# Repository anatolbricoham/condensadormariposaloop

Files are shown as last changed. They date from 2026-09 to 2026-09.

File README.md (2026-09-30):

# Loop magnética con condensador mariposa motorizado y autoajuste (DIY)

Cálculo completo, planos de corte láser (DXF/SVG), **piezas imprimibles en 3D (STL + OpenSCAD)**,
**firmware de autoajuste para ESP32** y guía de construcción de un **condensador variable de aire
tipo mariposa (butterfly)** para antenas **loop magnéticas de HF**, con la lista de materiales y
**dónde conseguirlos en Murcia**.

> 👉 **Empieza por la [guía paso a paso](docs/guia_paso_a_paso.md).**

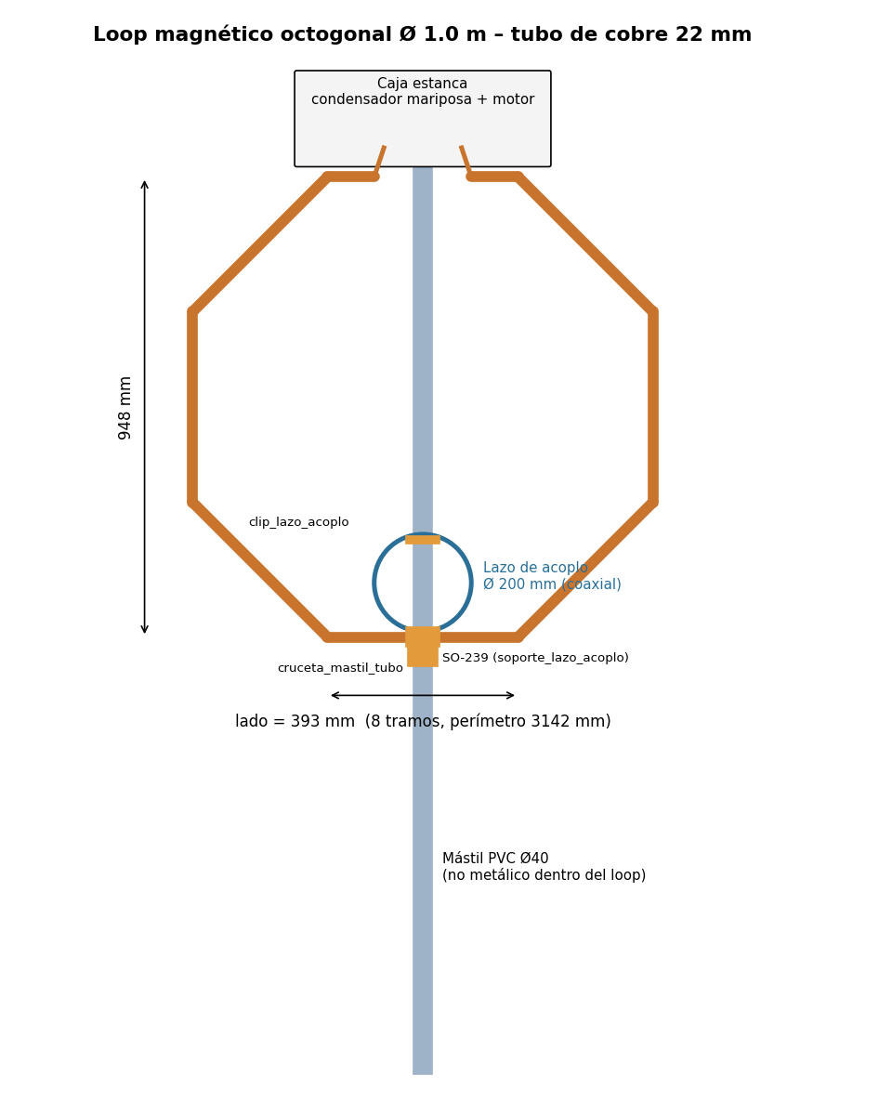
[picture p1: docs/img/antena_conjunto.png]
Antena completa


Basado en el artículo de **TA2WK** –
[High-Voltage DIY Air Capacitor for Magnetic Loop Antennas](https://www.ta2wk.com/high-voltage-diy-air-capacitor-for-magnetic-loop-antennas/)
– y en la serie de vídeos de referencia
([YouTube](https://www.youtube.com/watch?v=iPEKQIZHf5k&list=PLLFrLgZ4YFd04bd3ThvmXpGTpUq9JYBLg&index=1)).

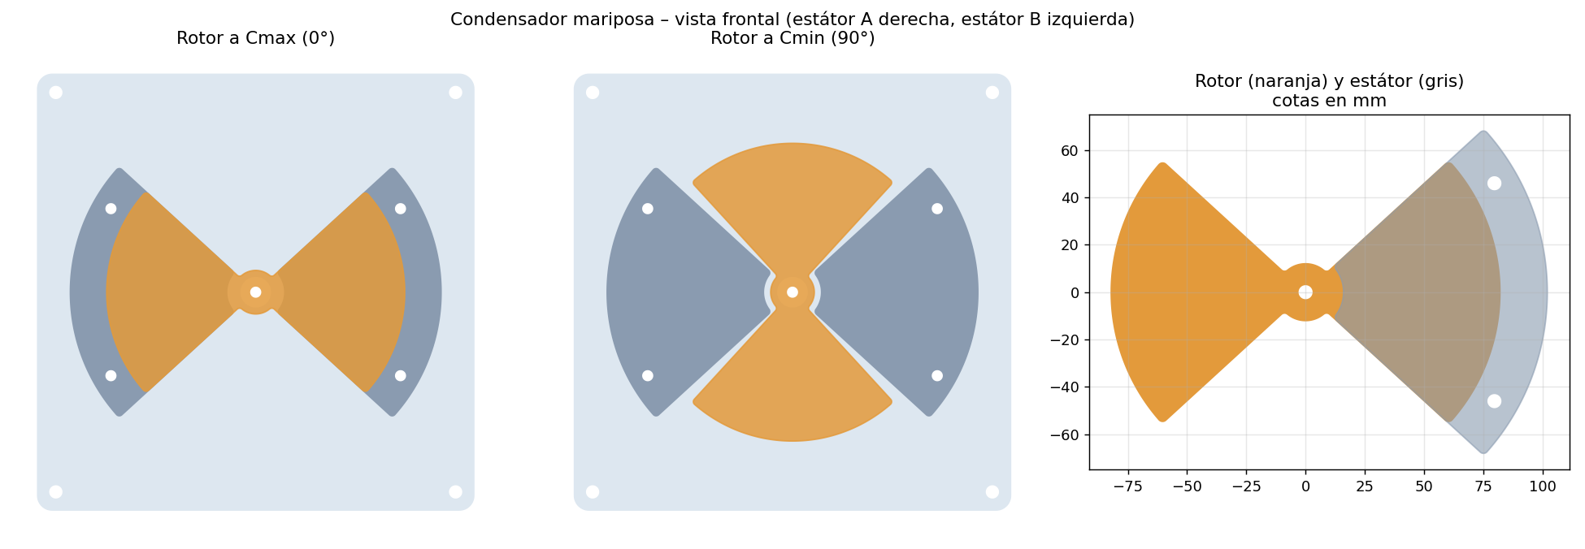
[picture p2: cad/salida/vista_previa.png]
Vista previa

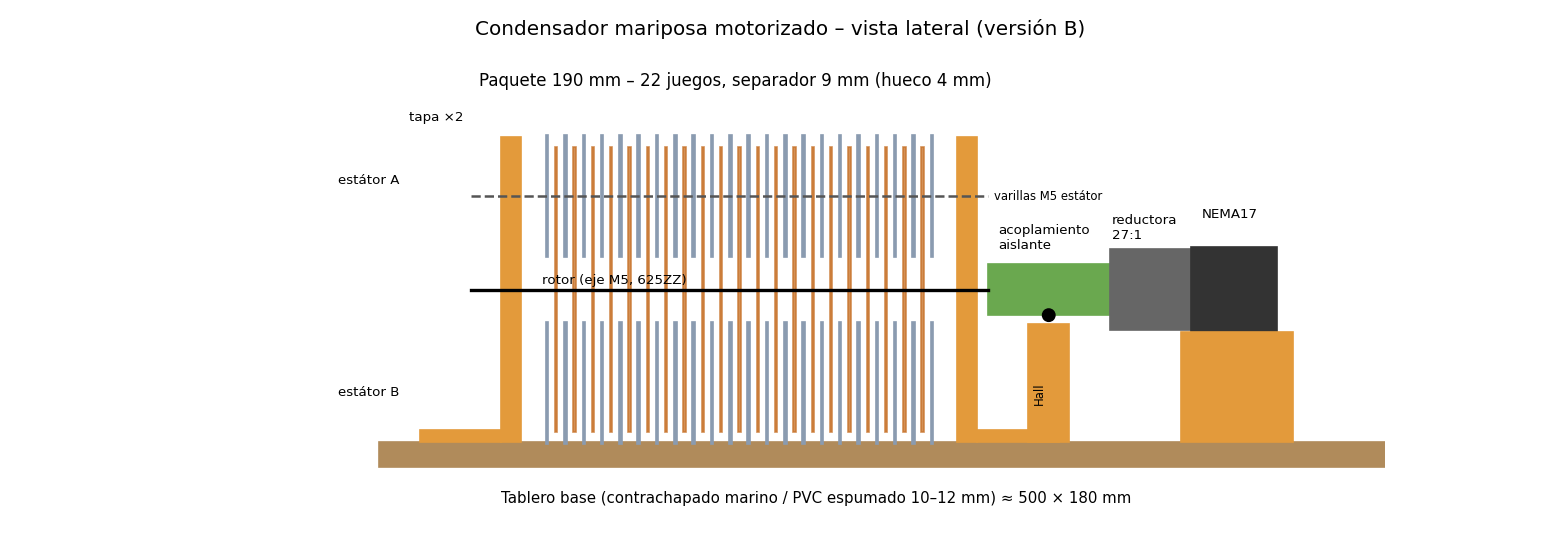
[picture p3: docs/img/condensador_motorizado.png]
Condensador motorizado


## Resumen del diseño

| | |
|---|---|
| Tipo | Mariposa (2 estátores en serie + rotor flotante, sin contactos deslizantes) |
| Placas | Aluminio 1 mm, corte láser. Lóbulo de 85°, R rotor 82 mm, estátor R16–R102 mm |
| Área de solape por lóbulo | 4 798 mm² |
| Recorrido | 90° de Cmax a Cmin |
| Estructura | Varillas M5 inox + separadores de tuerca/arandela, tapas de policarbonato 240×240 mm |
| Loop de referencia | **Ø 1,0 m, tubo de cobre 22 mm** (octógono con codos de 45°) · 40 m → 15/17 m |

### Tres versiones (loop Ø 1 m, tubo 22 mm)

| Versión | Hueco | Separador | Juegos (estátor/lado) | Placas rotor / estátor | Cmax ≈ | Cmin ≈ | V práctica | Potencia máx. (40 / 30 / 20 m) | Paquete |
|---|---|---|---|---|---|---|---|---|---|
| **A · QRP/portable** | 3 mm | 7 mm | 16 | 15 / 32 | 212 pF | 19 pF | 3,0 kV | 32 / 25 / 28 W | 106 mm |
| **B · 50 W** ⭐ | 4 mm | 9 mm | 22 | 21 / 44 | 223 pF | 20 pF | 4,3 kV | 66 / 52 / 57 W | 190 mm |
| **C · 100 W** | 5 mm | 11 mm | 27 | 26 / 54 | 221 pF | 20 pF | 5,9 kV | 124 / 97 / 107 W | 287 mm |

Detalle banda a banda: [`resultados/variantes.md`](resultados/variantes.md).
⭐ La versión B es el mejor compromiso tamaño/potencia para un equipo de 100 W usado a 50 W en digitales o 100 W en SSB con prudencia.

### El loop de Ø 1 m (22 mm) a 100 W

| Banda | C necesaria | Eficiencia | Ancho de banda | Tensión en el condensador |
|---|---|---|---|---|
| 40 m | 203 pF | 14 % (−8,5 dB) | 5,5 kHz | 5,3 kV rms |
| 30 m | 98 pF | 37 % (−4,3 dB) | 8,8 kHz | 6,0 kV rms |
| 20 m | 49 pF | 66 % (−1,8 dB) | 19 kHz | 5,7 kV rms |
| 17 m | 29 pF | 82 % (−0,8 dB) | 41 kHz | 5,0 kV rms |
| 15 m | 20 pF | 89 % (−0,5 dB) | 70 kHz | 4,4 kV rms |

Tablas completas para loops de 0,8 / 1,0 / 1,2 / 1,6 m en [`resultados/`](resultados/).

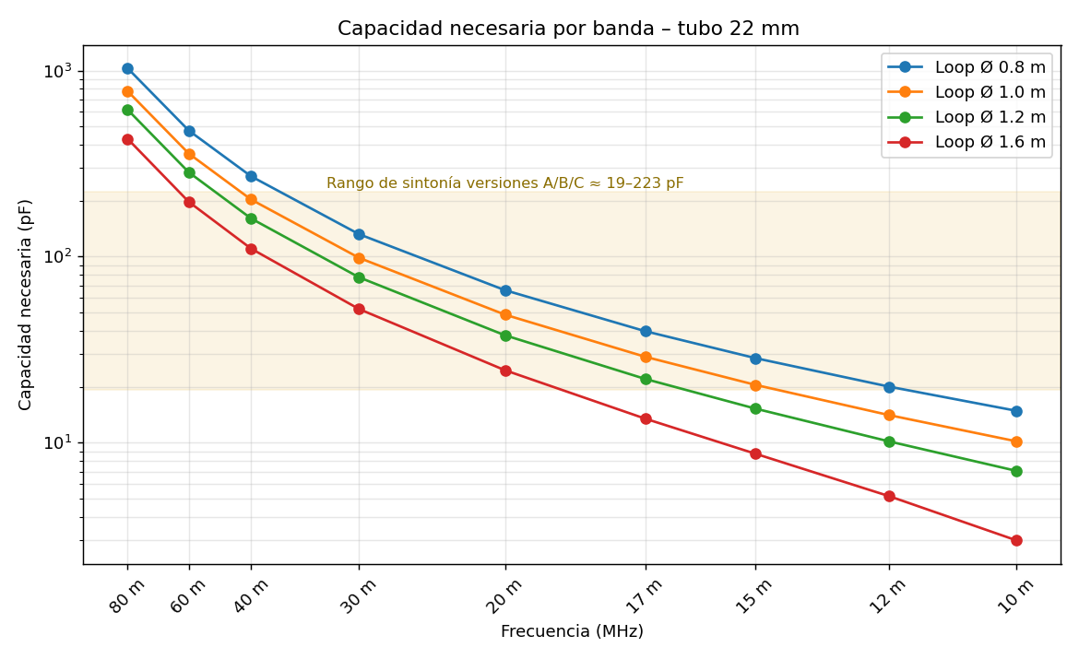
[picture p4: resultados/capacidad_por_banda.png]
Capacidad por banda

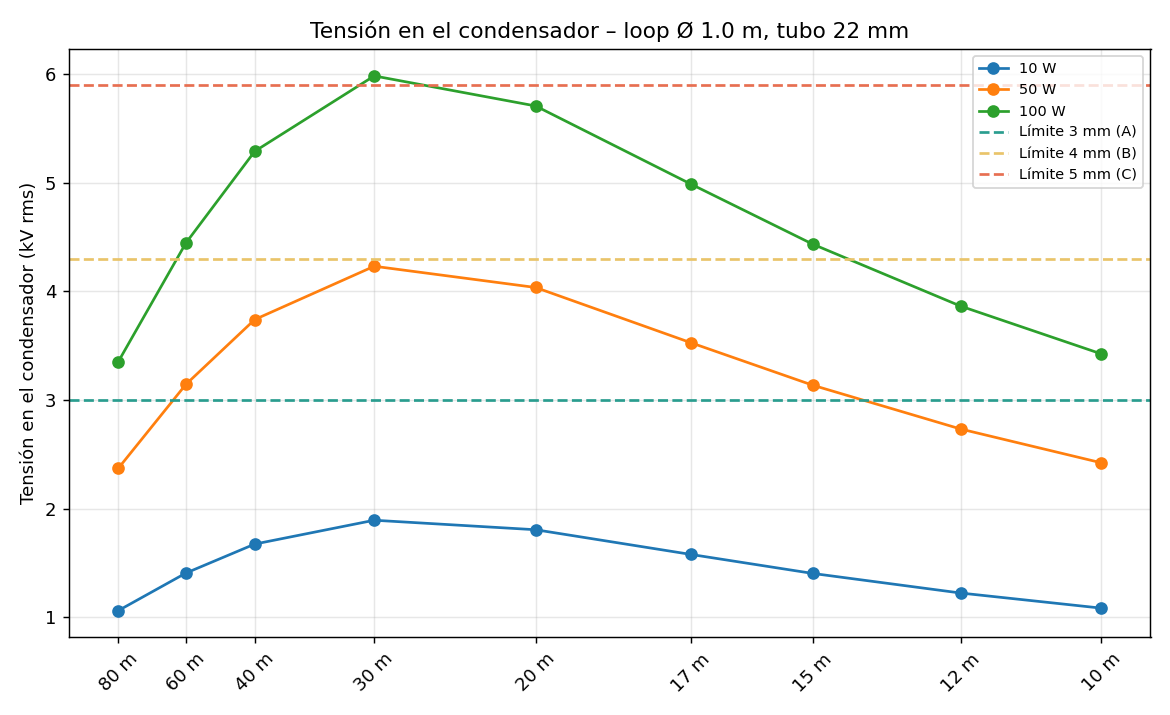
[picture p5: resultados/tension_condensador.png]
Tensión


### Comprobación con el artículo de TA2WK (hueco 3 mm)

| Juegos | Este modelo | TA2WK |
|---|---|---|
| 5 | 57 pF | 58 pF |
| 10 | 127 pF | 131 pF |
| 15 | 198 pF | 204 pF |
| 20 | 269 pF | 277 pF |
| 30 | 411 pF | 423 pF |

## Autoajuste motorizado

| | |
|---|---|
| Motor | NEMA17 + reductora planetaria 27:1 + TMC2209 a 1/16 → **240 pasos/grado** (0,17 kHz/paso en 40 m) |
| Referencia | Sensor Hall A3144 + imán en el acoplamiento aislante (home = Cmin) |
| Medida | Puente de ROE tipo Bruene (FT50-43) → ADC del ESP32 |
| Control | ESP32: 4 pulsadores, OLED, WiFi con página web, puerto serie, memoria por banda |
| Algoritmo | Barrido grueso → fino → paso a paso, aproximación siempre en el mismo sentido (anula la holgura) |

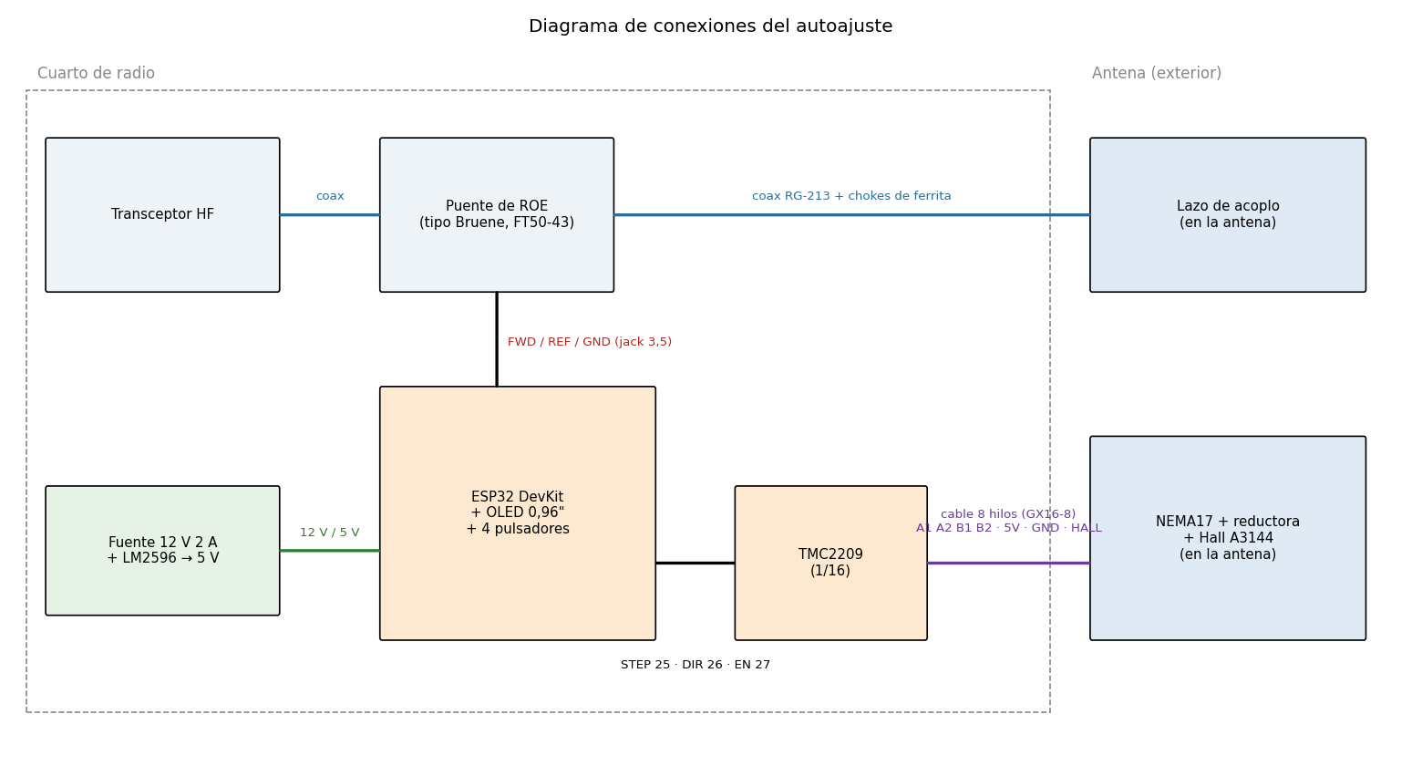
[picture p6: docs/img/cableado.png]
Cableado


### Piezas impresas en 3D

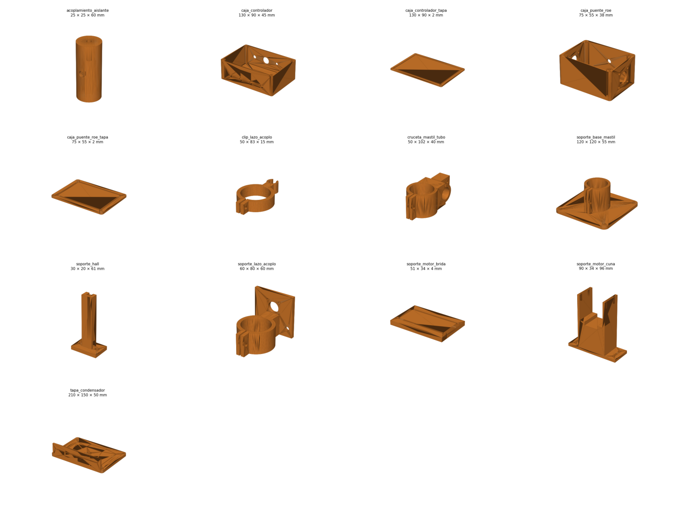
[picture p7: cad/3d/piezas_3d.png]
Piezas 3D


Tapas del condensador, acoplamiento aislante, cuna del motor, soporte del Hall, unión con el mástil,
cruceta del loop, soporte y clip del lazo de acoplo, y cajas del controlador y del puente de ROE.
Detalle y ajustes de impresión: [`cad/3d/PIEZAS.md`](cad/3d/PIEZAS.md).

## Estructura del repositorio

```
calc/modelo.py             Modelo físico (condensador + loop)
calc/calcular_todo.py      Tablas y gráficas en resultados/
cad/generar_planos.py      DXF de corte láser, SVG y vista previa en cad/salida/
cad/generar_3d.py          parametros.scad → STL + PNG (cad/3d/) + posiciones del motor + firmware/bandas.h
cad/generar_esquemas.py    Esquemas de conjunto y cableado (docs/img/)
cad/3d/scad/               Fuentes OpenSCAD paramétricos
cad/3d/stl/                STL listos para imprimir
firmware/autotune_loop/    Firmware ESP32 (Arduino)
firmware/test/             Simulación del autoajuste en el PC
resultados/                Tablas .md/.csv, lista de materiales, posiciones del motor, gráficas
docs/guia_paso_a_paso.md   ⭐ Guía completa de construcción con todos los datos
docs/montaje.md            Montaje detallado del condensador
docs/formulas.md           Fórmulas explicadas
docs/materiales_murcia.md  Dónde comprar cada cosa en Murcia
```

## Cómo recalcular para tu loop

```bash
pip install -r requirements.txt          # y OpenSCAD instalado para los STL
python calc/calcular_todo.py --diametro 1.2 --tubo 22 --potencia 100
python cad/generar_planos.py
python cad/generar_3d.py --version B --diametro 1.2
python cad/generar_esquemas.py
sh firmware/test/simular.sh              # opcional: prueba del autoajuste
```

Para cambiar la geometría de las placas edita `GeometriaPlacas` en `calc/modelo.py`
y vuelve a ejecutar ambos scripts (los DXF se regeneran solos).

## Materiales (resumen)

Placas de aluminio 1 mm por corte láser · 2 tapas impresas en PETG/ASA (o policarbonato por láser) ·
varilla roscada M5 inox + tuercas DIN 934 + arandelas DIN 125 inox · 2 rodamientos 625ZZ ·
acoplamiento aislante impreso · NEMA17 con reductora 27:1 + TMC2209 + ESP32 · tubo de cobre 22 mm + 8 codos de 45° ·
pletina de cobre · coaxial y conector.
Cantidades exactas: [`resultados/lista_materiales.md`](resultados/lista_materiales.md) ·
Tiendas y talleres en Murcia: [`docs/materiales_murcia.md`](docs/materiales_murcia.md).

## Limitaciones y avisos

- **Cmin es una estimación** (7 % de Cmax + 3 pF). Mídela con un LCR: si sale más alta, 15/12/10 m no
  sintonizarán con el loop de 1 m; quita placas o usa un loop menor para esas bandas.
- Las tensiones suponen un loop perfectamente adaptado y sin pérdidas extra en el condensador:
  son el **peor caso** (bueno para dimensionar).
- La tensión práctica sigue el criterio de TA2WK (≈1–1,2 kV/mm). Humedad, polvo y rebabas la reducen.
- **Peligro: alta tensión RF (varios kV).** Lee la sección de seguridad de [`docs/montaje.md`](docs/montaje.md).

## Publicar / clonar

```bash
git clone https://github.com/TU_USUARIO/condensador-mariposa-loop.git
```

Para publicar tu copia: crea un repositorio vacío en GitHub y ejecuta `sh publicar.sh URL` (o `publicar.bat URL` en Windows).

## Créditos y licencia

- Diseño original y tabla de referencia: TA2WK. Modelo de cálculo, planos y documentación: este repositorio.
- Código bajo licencia MIT; documentación y planos bajo CC BY-SA 4.0. Ver [`LICENSE`](LICENSE).

73!

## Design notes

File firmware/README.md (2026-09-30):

# Firmware de autoajuste (ESP32)

| Fichero | Qué es |
|---|---|
| `autotune_loop/autotune_loop.ino` | Programa principal: motor, home, medida de ROE, autoajuste, pulsadores, OLED, web |
| `autotune_loop/config.h` | Pines y parámetros (holgura, velocidades, umbrales, WiFi) |
| `autotune_loop/bandas.h` | **Generado** por `cad/generar_3d.py`: posiciones calculadas de cada banda |
| `test/simular.sh` | Compila el firmware en el PC (g++) con cabeceras simuladas y simula un autoajuste |

## Algoritmo

1. **Home**: baja hasta el flanco del sensor Hall → posición 0 = Cmin.
2. **Barrido grueso** ascendente de ±8° alrededor de la posición aprendida (o del preset) con saltos de ¼ del ancho de banda.
3. Si la ROE no baja de 4, **barrido completo** de 0 a 95°.
4. **Barrido fino** alrededor del mejor punto y **pasada final paso a paso**.
5. **Aproximación final siempre subiendo**: si hay que retroceder, se baja `HOLGURA` pasos de más y se vuelve a subir, para que la holgura de la reductora no afecte.
6. Se **desactiva el driver** (sin ruido ni consumo) y la posición se **guarda** en la memoria flash del ESP32 para esa banda.

Simulación incluida (resonancia de 32 pasos de ancho y 300 pasos de holgura): el autoajuste acaba en la resonancia exacta.

## Compilar

Arduino IDE 2 → placa **ESP32 Dev Module** (paquete *esp32* de Espressif) → librerías *Adafruit SSD1306* y *Adafruit GFX*.
Con PlatformIO: `platform = espressif32`, `board = esp32dev`, `framework = arduino`.
Pon `USAR_OLED 0` o `USAR_WIFI 0` en `config.h` si no usas esas funciones.

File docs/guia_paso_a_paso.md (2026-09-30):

# Guía paso a paso: loop magnética con condensador mariposa motorizado y autoajuste

Esta guía reúne **todos los datos calculados** en el repositorio y explica, en orden, cómo
construir una antena loop magnética de HF de **Ø 1 m** con un **condensador mariposa de aire**
movido por un **motor paso a paso** y un **controlador ESP32 que se ajusta solo** (busca la ROE
mínima). Las piezas de plástico se imprimen en 3D y las placas metálicas se cortan por láser.

Antena completa

---

## 0. Qué vas a construir: datos clave

| Parte | Valor |
|---|---|
| Loop | Octógono de **Ø 1,0 m** (948 mm entre lados), tubo de **cobre de 22 mm**, perímetro 3 142 mm, lado 393 mm |
| Bandas | **40, 30, 20, 17 y 15 m** (12 y 10 m solo si la Cmin real sale por debajo de 14 pF) |
| Condensador | Mariposa **versión B**: 22 juegos, hueco 4 mm, separador 9 mm, **≈ 20–223 pF**, **4,3 kV rms** |
| Potencia máxima | ≈ **50 W** continuos (FT8/RTTY); 66 W en 40 m, 94 W en 15 m (ver tabla §13) |
| Motor | NEMA17 + reductora planetaria **27:1**, driver TMC2209 a 1/16 → **240 pasos por grado** |
| Resolución | 0,17 kHz/paso en 40 m; 1,4 kHz/paso en 20 m (el ancho de banda es 5,5 y 19 kHz) |
| Control | ESP32 + puente de ROE + OLED + 4 pulsadores + página web por WiFi |
| Referencia | Sensor Hall A3144 + imán en el acoplamiento (home = Cmin) |

Condensador motorizado

> ¿Quieres otra potencia o tamaño? Ejecuta `python calc/calcular_todo.py --diametro X --potencia Y`
> y `python cad/generar_3d.py --version A|B|C`: se regeneran tablas, STL y `bandas.h`.

---

## 1. Lista de compra completa

Precios orientativos (2026). Dónde comprar en Murcia: [`materiales_murcia.md`](materiales_murcia.md).

### 1.1 Condensador (versión B)

| Material | Cantidad | Dónde | € aprox. |
|---|---|---|---|
| Placas de aluminio 1 mm cortadas por láser: `rotor.dxf` | 21 + 3 de repuesto | Taller de corte láser (Murcia/Molina) | 30–50 |
| Placas de aluminio 1 mm: `estator.dxf` | 44 + 4 de repuesto | Íd. | 50–80 |
| Varilla roscada M5 inox A2, 1 m | 2 (salen 4 × 280 mm + eje 350 mm) | Obramat / ferretería industrial | 8 |
| Tuercas M5 DIN 934 inox | caja de 200 + 50 | Íd. | 10 |
| Arandelas M5 DIN 125 inox | caja de 200 | Íd. | 5 |
| Rodamientos 625ZZ (5×16×5) | 2 | Tienda de impresión 3D / online | 3 |
| Collarines de 5 mm (o doble tuerca M5) | 2 | Online | 3 |
| Varilla roscada M6 de nylon + 8 tuercas nylon (tirantes) | 4 × 260 mm | Online / suministro industrial | 8 |
| Pletina o malla de cobre 20–25 mm | 1 m | Electrónica Llorga / chatarrería de cobre | 8 |
| Tornillos pasamuros de latón M6 × 40 + tuercas y arandelas | 2 | Ferretería | 3 |
| Terminales de ojal de cobre 16 mm² M6 | 4 | Material eléctrico | 3 |

### 1.2 Motorización y caja de la antena

| Material | Cantidad | Dónde | € aprox. |
|---|---|---|---|
| Motor NEMA17 con reductora planetaria 27:1 (salida Ø 8 mm) | 1 | Online (StepperOnline, AliExpress, Amazon) | 30–40 |
| Sensor Hall A3144 + imán de neodimio 6×3 mm | 1 + 2 | Electrónica Llorga / online | 3 |
| Tornillos prisioneros M3 × 6 + tuercas M3 | 2 + 2 | Ferretería | 1 |
| Tablero base contrachapado marino o PVC espumado 10–12 mm | 500 × 180 mm | Obramat / Leroy Merlin (corte a medida) | 8 |
| Tornillos M4 inox (o nylon junto al rotor) | 16 | Ferretería | 3 |
| Caja estanca o caja de plástico grande (tapa hacia abajo) ≥ 520 × 200 × 200 mm | 1 | Obramat / Leroy Merlin | 15–30 |
| Conector aviación GX16-8 (macho + hembra) | 2 juegos | Electrónica Llorga / online | 6 |
| Cable de 8 hilos (alarma, 0,22 mm²; ≥ 0,5 mm² si pasa de 15 m) | lo que mida la bajada | Material eléctrico | 1/m |
| Ferritas de clip mezcla 31 (para el cable de control y el coaxial) | 6 | Online / tiendas de radio | 10 |

### 1.3 Loop, mástil y acoplo

| Material | Cantidad | Dónde | € aprox. |
|---|---|---|---|
| Tubo de cobre rígido 22 mm, barra de 2,5 m | 2 | Obramat / BigMat / fontanería | 40–60 |
| Codos de cobre 45° para soldar, 22 mm | 8 | Íd. | 10 |
| Soldadura de plata (varilla 15–40 % Ag) + desoxidante, o estaño-plata de fontanería | 1 | Íd. | 10–25 |
| Tubo de PVC de presión Ø 40 mm (mástil) | 2 m | Fontanería | 6 |
| Conector SO-239 de brida cuadrada | 1 | Electrónica Llorga | 3 |
| Coaxial RG-213 (lazo de acoplo, 0,65 m) + bajada | 0,7 m + bajada | Íd. | 3/m |
| Bridas UV negras | 1 bolsa | Ferretería | 3 |

### 1.4 Controlador (cuarto de radio)

| Material | Cantidad | € aprox. |
|---|---|---|
| ESP32 DevKit v1 (38 pines) | 1 | 8 |
| Driver TMC2209 (BigTreeTech o similar) + disipador | 1 | 6 |
| Pantalla OLED 0,96" SSD1306 I2C | 1 | 4 |
| Pulsadores de panel de 7 mm | 4 | 3 |
| Fuente 12 V 2 A + convertidor LM2596 (ajustado a 5 V) | 1 + 1 | 12 |
| Condensador electrolítico 100 µF 35 V (junto al TMC2209) | 1 | 0,5 |
| Placa perforada 5 × 7 cm, tiras de pines hembra, jack DC de panel 5,5/2,1 | 1 | 4 |
| Resistencias 10 kΩ ×5, 1 kΩ ×2, 100 Ω 1 W ×2 | — | 1 |
| Zener 3,3 V (BZX55C3V3) ×2, condensadores 100 nF ×4, 10 nF ×2 | — | 1 |
| **Puente de ROE**: toroide FT50-43, hilo esmaltado 0,4–0,5 mm (1 m), 2 diodos 1N5711 (o BAT41), trimmer cerámico 5–30 pF, condensador 330 pF 500 V NP0/mica, 2 SO-239, jack 3,5 mm estéreo | 1 juego | 12 |

Los toroides FT50-43 y los diodos 1N5711 no suelen estar en tiendas físicas: tiendas online
de radioafición o AliExpress, o pregunta en el **Radio Club Región de Murcia (EA5RCZ)**.

### 1.5 Filamento

≈ **1 kg de PETG o ASA** (las dos tapas del condensador se llevan unos 500 g) + 150 g de PLA
para las cajas del cuarto de radio. **No uses PLA en el exterior**: se deforma al sol de Murcia.

---

## 2. Herramientas

Impresora 3D (cama ≥ 220 × 220 mm), calibre, soldador de 40–60 W, soplete (gas MAPP o propano),
cortatubos, lima y lija 400–600, taladro, llaves de 8 y 10 mm, multímetro, **NanoVNA o analizador
de antena**, **carga fantasma de 50 Ω** y, a ser posible, medidor LCR (medidor de capacidad).

---

## 3. Fase 1 — Imprimir las piezas 3D

Los ficheros listos están en [`cad/3d/stl/`](../cad/3d/stl) y los fuentes paramétricos (OpenSCAD) en
[`cad/3d/scad/`](../cad/3d/scad). Vista de todas las piezas: [`cad/3d/PIEZAS.md`](../cad/3d/PIEZAS.md).

| Pieza | Cant. | Material | Relleno | Orientación / notas |
|---|---|---|---|---|
| `tapa_condensador` | **2** | PETG/ASA | 40 % gyroid, 5 perímetros | Cara lisa en la cama; el pie queda hacia arriba (sin soportes). 8–15 h c/u |
| `acoplamiento_aislante` | 1 | PETG | **100 %** | De pie. Es el aislante del rotor: sin huecos |
| `soporte_motor_cuna` | 1 | PETG | 30 % | Sobre el pie |
| `soporte_motor_brida` | 1 | PETG | 40 % | Plana |
| `soporte_hall` | 1 | PETG | 40 % | De pie |
| `soporte_base_mastil` | 1 | ASA/PETG | 50 % | Placa en la cama, collar hacia arriba |
| `cruceta_mastil_tubo` | 1 | ASA/PETG | 50 % | Soportes solo en el agujero del tubo |
| `soporte_lazo_acoplo` | 1 | ASA/PETG | 50 % | Collar en la cama |
| `clip_lazo_acoplo` | 1 | ASA/PETG | 40 % | Ajusta `d_cable` en el .scad si no usas RG-213 |
| `caja_controlador` + `_tapa` | 1 + 1 | PLA/PETG | 20 % | Abierta hacia arriba |
| `caja_puente_roe` + `_tapa` | 1 + 1 | PLA/PETG | 20 % | Abierta hacia arriba |

Ajustes generales: capa 0,2 mm, boquilla 0,4 mm, 4–5 perímetros, sin ventilador (ASA) o 30 % (PETG).

**Después de imprimir:**

1. Prueba los rodamientos 625ZZ en las tapas: deben entrar a presión suave (si no, lija o imprime con un 0,5 % más de escala XY).
2. Pasa una broca de 5,5 mm por los agujeros de las varillas y una de 6,5 mm por los de los tirantes.
3. Mete una tuerca M3 en cada ranura del acoplamiento y rosca los prisioneros.
4. Pega el imán de 6×3 mm en su alojamiento del acoplamiento con cianoacrilato.
5. Para cambiar medidas (mástil de Ø 32, tubo de 18 mm…), edita `PARAM` en `cad/generar_3d.py` y ejecútalo: se regeneran todos los STL.

---

## 4. Fase 2 — Cortar las placas por láser

1. Lleva a un taller (lista en [`materiales_murcia.md`](materiales_murcia.md)) los ficheros
   [`cad/salida/rotor.dxf`](../cad/salida/rotor.dxf) y [`cad/salida/estator.dxf`](../cad/salida/estator.dxf).
2. Pide **aluminio de 1 mm**, **24 rotores y 48 estátores** (con repuestos), **desbarbados** y **sin doblar**.
3. Al recogerlos: comprueba que todas las placas son planas, lija los cantos (400 → 600) y límpialas con alcohol isopropílico.

Geometría: lóbulo de 85°, R rotor 82 mm, estátor de R16 a R102 mm, varillas M5 a R92 mm ±30°,
área de solape por lóbulo 4 798 mm².

---

## 5. Fase 3 — Montar el condensador

Procedimiento detallado en [`montaje.md`](montaje.md). Resumen con las piezas impresas:

1. **Varillas de los estátores**: corta 4 tramos de M5 de **280 mm**. Pásalos por la tapa trasera (2 a cada lado) con tuerca y arandela por fuera y por dentro.
2. Deja **12 mm** entre la cara interior de la tapa y la primera placa de estátor (2 tuercas + 4 arandelas).
3. Apila en cada lado **22 placas de estátor** separadas por **9 mm** (2 tuercas + 1 arandela). Comprueba con el calibre cada 5 placas.
4. **Rotor**: en el eje M5 de **350 mm** monta las **21 placas de rotor** separadas también por 9 mm, con los lóbulos alineados. Bloquéalas con collarín o doble tuerca en cada extremo.
5. Mete los rodamientos 625ZZ en ambas tapas, introduce el rotor girado 90° (posición Cmin), coloca la tapa delantera y cierra con los **4 tirantes de nylon M6**.
6. **Centra el rotor**: a Cmax cada placa de rotor debe quedar a **4,0 mm** de sus dos estátores vecinos. Ajusta con las tuercas del eje hasta que gire 360° sin rozar.
7. **Pruebas**: sin continuidad entre A, B y el rotor. Con el LCR anota **Cmin** (rotor a 90°) y **Cmax** (0°). Esperado: ≈ 20 / 223 pF.

---

## 6. Fase 4 — Motorización

1. Atornilla las dos tapas (por sus pies) al **tablero base** de 500 × 180 mm, con el eje paralelo al lado largo.
2. Sujeta el motor en la **cuna** con la **brida** (4 tornillos M3 de rosca-chapa). El eje de la reductora queda a **75 mm** de la base, la misma altura que el eje del condensador.
3. Une los ejes con el **acoplamiento aislante** (lado de Ø 8 mm al motor, de Ø 5 mm al rotor). Deja **≥ 5 mm** de hueco entre la tapa y el acoplamiento.
4. **Alinea**: gira a mano la salida de la reductora; el condensador no debe cabecear. Si lo hace, calza la cuna.
5. Atornilla el **soporte del Hall** bajo el acoplamiento: la cara del A3144 debe quedar a **1,5 mm** del plástico. Gira el rotor a **Cmin** y coloca el imán justo encima del sensor en esa posición.
6. Pasa el cable de 8 hilos por un prensaestopas de la caja y ponle el conector GX16-8.

| Hilo GX16-8 | Señal |
|---|---|
| 1, 2 | Bobina A del motor (A1, A2) |
| 3, 4 | Bobina B del motor (B1, B2) |
| 5 | +5 V (alimentación del A3144, patilla 1) |
| 6 | GND (A3144 patilla 2) |
| 7 | HALL (A3144 patilla 3, salida) |
| 8 | Reserva / malla |

Identifica las bobinas del motor con el multímetro: los dos hilos con continuidad entre sí forman una bobina.

---

## 7. Fase 5 — El loop de cobre

Antena

1. **Medidas**: octógono de lado **393 mm** entre centros de codo. Mide en tus codos la distancia *z* del centro del codo al fondo del casquillo (suele ser 8–12 mm). **Longitud de corte = 393 − 2·z** (con z = 10 → **373 mm**).
2. **Corta 7 tramos** de 373 mm (los 6 lados inclinados/verticales y el de abajo) y **2 tramos cortos** para el lado superior: cada uno de (393 − 200)/2 − z ≈ **86 mm**. Así queda un hueco de **200 mm** arriba para el mástil y el condensador.
3. Aplana 20 mm del extremo libre de cada tramo corto (tornillo de banco) y taládralo a 6,5 mm.
4. **Suelda** los 8 codos con soldadura fuerte de plata (o estaño-plata bien caliente). Limpia y aplica desoxidante: **cada soldadura mala son miliohmios de pérdida**, y con 100 W hay 25–50 A circulando.
5. Comprueba sobre el suelo que el octógono es plano.
6. Monta el **mástil de PVC Ø 40** atravesando el loop: la **cruceta** sujeta el lado de abajo y la **caja del condensador** va arriba, sobre el `soporte_base_mastil`.
7. Pasa los tornillos **pasamuros de latón M6** por las paredes de la caja; por fuera se atornillan los extremos aplanados del loop y por dentro la pletina de cobre hasta las varillas de los estátores A y B. **Conexiones lo más cortas y anchas posible.**

---

## 8. Fase 6 — Lazo de acoplo (Faraday)

1. Corta **0,65 m de RG-213** (lazo de **Ø 200 mm = D/5**).
2. En el punto **opuesto al conector** (arriba) quita 10 mm de malla: el vivo sigue entero y la malla queda cortada.
3. En el conector: el **vivo de un extremo va al centro** del SO-239 y la malla de ese extremo a masa. En el **otro extremo** suelda **vivo y malla juntos a masa**.
4. Monta el SO-239 en el `soporte_lazo_acoplo`, justo encima de la cruceta, y sujeta la parte alta del lazo con el `clip_lazo_acoplo`.
5. El lazo debe quedar **en el plano del loop** y tocando (sin contacto eléctrico) el lado inferior.

---

## 9. Fase 7 — Electrónica

Cableado

### 9.1 Controlador (ESP32)

| ESP32 | Conecta a |
|---|---|
| GPIO 25 | TMC2209 STEP |
| GPIO 26 | TMC2209 DIR |
| GPIO 27 | TMC2209 EN |
| GPIO 23 | HALL (con **10 kΩ a 3,3 V** y 100 nF a GND) |
| GPIO 32 / 33 / 18 / 19 | Pulsadores ARRIBA / ABAJO / TUNE / BANDA (el otro lado a GND) |
| GPIO 36 (VP) | FWD del puente (a través de 1 kΩ; zener 3,3 V a GND) |
| GPIO 39 (VN) | REF del puente (a través de 1 kΩ; zener 3,3 V a GND) |
| GPIO 21 / 22 | OLED SDA / SCL |
| 5V / GND | Salida del LM2596 ajustada a **5,0 V** |

**TMC2209**: VM = 12 V (con el electrolítico de 100 µF lo más cerca posible), VIO = 3,3 V,
**MS1 y MS2 a 3,3 V (1/16)**, salidas A1-A2-B1-B2 al GX16-8. Ajusta la **Vref ≈ 0,9–1,0 V
(≈ 0,7 A)** con el potenciómetro antes de conectar el motor.

### 9.2 Puente de ROE (tipo Bruene)

Se monta en su caja entre el transceptor y la bajada de coaxial. Es un transformador de
corriente más un divisor capacitivo:

```
 SO-239 TX ●────────┬───────────( T1 )───────────● SO-239 ANT
                    │     el vivo pasa por el centro de T1 = 1 espira
                   C1  trimmer 5–30 pF
                    │
                    ├──────────── toma central del secundario de T1
                    │
                   C2  330 pF
                    │
                   GND

 Secundario de T1: 20 espiras en FT50-43, toma central en la espira 10,
 100 Ω entre los extremos A y B.

   extremo A ──|>|── 1N5711 ──┬──── 10 kΩ ──┬──── 1 kΩ ──┬── FWD (GPIO 36)
                             10 nF         10 kΩ          zener 3,3 V
                              │             │             │
                             GND           GND           GND

   extremo B ──|>|── 1N5711 ── (mismo circuito) ────────── REF (GPIO 39)
```

Cálculo: en cada extremo aparece `Vc ± I·R/(2N)`. Con N = 20, R = 100 Ω y una carga de 50 Ω,
`I·R/(2N) = V/20`; si el divisor da `Vc = V/20` (C1 ≈ 17 pF con C2 = 330 pF), un extremo
vale V/10 (directa) y el otro 0 (reflejada).

- **T1**: toroide FT50-43 con **20 espiras** de hilo esmaltado de 0,5 mm y **toma central** (en la espira 10). Entre los dos extremos, **100 Ω** (2 × 51 Ω o 2 × 47 Ω en serie; 1 W).
- La **toma central** va al punto medio del divisor **C1 (trimmer 5–30 pF) / C2 (330 pF)**, que toma tensión de la línea.
- Con 50 Ω en la salida, un extremo da la tensión directa (≈ V/10) y el otro se anula: ese es **REF**.
- Con 10 W, FWD ≈ 1,5 V en el ADC; admite hasta ~30 W sin saturar. Las zener de 3,3 V protegen el ESP32 cuando emites a 100 W.

**Calibración**: pon la **carga fantasma** en ANT, emite 5–10 W y gira **C1 hasta que REF sea
mínimo** (≈ 0 V). Si el mínimo sale en el otro extremo, intercambia los cables FWD/REF.

---

## 10. Fase 8 — Firmware

1. Instala el **Arduino IDE 2**, añade el gestor de placas `https://espressif.github.io/arduino-esp32/package_esp32_index.json` e instala **esp32 (Espressif)**.
2. Instala las librerías **Adafruit SSD1306** y **Adafruit GFX** (Gestor de librerías).
3. Abre [`firmware/autotune_loop/autotune_loop.ino`](../firmware/autotune_loop/autotune_loop.ino). Placa: **ESP32 Dev Module**.
4. Revisa [`config.h`](../firmware/autotune_loop/config.h): pines, contraseña de la WiFi (`73loop73`) y umbrales.
5. [`bandas.h`](../firmware/autotune_loop/bandas.h) contiene las posiciones calculadas; se regenera con `python cad/generar_3d.py`.
6. Compila y sube. En el monitor serie (115200) verás `Loop Tuner listo`.

Sin hardware, puedes probar la lógica del autoajuste en el PC con [`firmware/test/simular.sh`](../firmware/test/simular.sh):
compila el firmware con g++ y simula una resonancia con 300 pasos de holgura en la reductora.

---

## 11. Fase 9 — Pruebas y puesta a punto

1. **Sin RF, motor en la mesa**: al arrancar el ESP32 busca el home. Si gira al revés (se aleja del imán), pon `INVERTIR_DIR 1`.
2. **Holgura**: mueve ±1000 pasos y observa el rotor; si la holgura de tu reductora supera 1,5° (360 pasos), sube `HOLGURA` en `config.h`.
3. **Con el analizador** en el lazo de acoplo (antena ya montada, mejor a su altura definitiva):
   - Selecciona 40 m. El motor va al preset (19 554 pasos). Retoca con ARRIBA/ABAJO hasta ver la resonancia en el NanoVNA y pulsa *Guardar* en la web (o `g` por serie).
   - Ajusta la **forma del lazo de acoplo** (más redondo/ovalado, más cerca o lejos del tubo) hasta conseguir ROE < 1,5.
   - Repite en 30, 20, 17 y 15 m.
4. **Primer autoajuste con RF**: conecta el puente, pon el equipo en **5 W de portadora** (FM/AM/CW o TUNE) y pulsa TUNE. Tarda 2–15 s. Al terminar, el motor se desconecta (sin ruido ni consumo) y la posición queda guardada.
5. Sube la potencia poco a poco escuchando si chisporrotea: **nunca por encima de la potencia máxima de la tabla §13**.

---

## 12. Uso diario

| Acción | Botón | Web / serie |
|---|---|---|
| Cambiar de banda (va a la posición aprendida) | BANDA | desplegable / `b<n>`, `n` |
| Autoajuste (con portadora de 5–10 W) | TUNE (corto) | AUTO TUNE / `t` |
| Retoque fino | ARRIBA / ABAJO (mantener = continuo) | « » / `u`, `d` (×10: `U`, `D`) |
| Guardar la posición actual para la banda | — | Guardar / `g` |
| Buscar home | TUNE mantenido 2 s | Home / `h` |
| Ir a una posición concreta | — | `p<pasos>` |

Web: conéctate a la WiFi **LoopTuner** (clave `73loop73`) y abre **http://192.168.4.1** desde el móvil.

Dentro de una banda: con el ancho de banda de la loop (5,5 kHz en 40 m) hay que reajustar
cada vez que te muevas más de 2–3 kHz. En 40 m cada paso mueve 0,17 kHz; en 20 m, 1,4 kHz.

---

## 13. Tabla de datos (loop Ø 1 m, tubo 22 mm, condensador versión B)

| Banda | C necesaria | Ángulo desde Cmin | Paso preset | kHz/paso | Ancho de banda | Eficiencia | Tensión a 50 W | Potencia máx. |
|---|---|---|---|---|---|---|---|---|
| 40 m | 203 pF | 81,5° | 19 554 | 0,17 | 5,5 kHz | 14 % (−8,5 dB) | 3,7 kV | 66 W |
| 30 m | 98 pF | 37,8° | 9 064 | 0,50 | 8,8 kHz | 37 % (−4,3 dB) | 4,2 kV | 52 W |
| 20 m | 49 pF | 16,9° | 4 061 | 1,37 | 19 kHz | 66 % (−1,8 dB) | 4,0 kV | 57 W |
| 17 m | 29 pF | 8,6° | 2 068 | 2,86 | 41 kHz | 82 % (−0,8 dB) | 3,5 kV | 74 W |
| 15 m | 20 pF | 5,1° | 1 214 | 4,57 | 70 kHz | 89 % (−0,5 dB) | 3,1 kV | 94 W |

Tablas completas: [`resultados/loop_1m.md`](../resultados/loop_1m.md),
[`resultados/variantes.md`](../resultados/variantes.md), [`resultados/posiciones_motor.md`](../resultados/posiciones_motor.md).

---

## 14. Problemas frecuentes

| Síntoma | Causa probable / solución |
|---|---|
| "ERROR: sin home" | Imán lejos del sensor (> 3 mm), sensor sin 5 V, falta el pull-up de 10 kΩ |
| "Sin portadora" | No estás emitiendo, potencia < 3 W o FWD/REF cruzados |
| No encuentra la ROE mínima en una banda | Cmin real demasiado alta (15 m) → quita 2–3 placas de rotor; o fuera de rango en 40 m → añade placas |
| ROE mínima 2–3 | Ajusta el lazo de acoplo (forma y distancia), no el condensador |
| El ajuste se desplaza con el tiempo | Holgura: sube `HOLGURA`; prisioneros flojos en el acoplamiento |
| Chasquidos/arcos al transmitir | Rebabas, polvo o humedad; baja potencia; limpia y seca la caja |
| Ruido en recepción | El driver queda activo: comprueba EN (GPIO 27); ferritas en el cable de 8 hilos |
| La resonancia cambia con la lluvia | Normal en loops: reajusta (para eso está el autoajuste) |

---

## 15. Seguridad

- **Alta tensión de RF**: 3–6 kV en el condensador y en los extremos del loop. Nunca toques la antena transmitiendo.
- **Exposición**: campo magnético intenso cerca del loop. A 50–100 W mantén **≥ 3 m** de personas; consulta los límites del RD 1066/2001.
- Transmite los primeros minutos a baja potencia y comprueba la temperatura de las uniones.
- La caja del condensador debe ser **estanca y con desagüe** (un agujero pequeño abajo) para que no se condense agua.
- Protege el mástil y la bajada contra rayos; desconecta la antena cuando haya tormenta.

73 y buena construcción.

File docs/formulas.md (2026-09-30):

# Fórmulas usadas

Todo está implementado en [`calc/modelo.py`](../calc/modelo.py). Unidades SI.

## 1. Condensador mariposa

Un condensador mariposa tiene **dos grupos de estátor (A y B)** y **un rotor común flotante**.
La RF entra por A, pasa al rotor a través del aire y sale por B, así que **no hay contacto
deslizante** (sin escobillas ⇒ sin pérdidas ni ruido) y los dos grupos quedan **en serie**.

Con `N` = nº de juegos (placas de estátor por lado, criterio del artículo TA2WK):

| Magnitud | Fórmula |
|---|---|
| Placas de rotor | `N − 1` |
| Huecos de aire por grupo | `2·(N − 1)` |
| Área de solape de un lóbulo | `A = ½·θ·(R_rotor² − r_int²)` (θ en rad) |
| Capacidad de un hueco | `C_h = ε₀·A / d` |
| Capacidad de un grupo | `C_g = 2·(N−1)·C_h` |
| **Capacidad total (A y B en serie)** | **`C_max = C_g / 2 = (N−1)·ε₀·A/d`** |
| Separador entre placas de estátor | `s = 2·d + t` (t = espesor de chapa) → TA2WK: `d = (s − t)/2` |
| Corrección de bordes (estimación) | `k = 1 + d/(π·w)·(1 + ln(2π·w/d))`, w = ancho radial del lóbulo |
| Capacidad mínima (estimación empírica) | `C_min ≈ 0,07·C_max + 3 pF` |

Con la geometría del repo (θ = 85°, R_rotor = 82 mm, r_int = 16 mm) → A = 4 798 mm² y
con d = 3 mm la tabla coincide con la de TA2WK dentro de ±3 %.

### Tensión

- Ruptura teórica del aire seco: ~3 kV/mm (campo uniforme, DC). En RF, con bordes, polvo
  y humedad (Murcia en verano ≈ 60–70 % HR en costa) hay que derratear mucho.
- Criterio práctico (tabla TA2WK): 3 mm → 3 000 V · 4 mm → 4 300 V · 5 mm → 5 900 V · 6 mm → 7 400 V.
- En la mariposa la tensión del loop se reparte entre los dos huecos en serie (A-rotor y
  rotor-B), lo que da margen extra frente a un condensador normal con el mismo hueco.

## 2. Loop magnético

| Magnitud | Fórmula |
|---|---|
| Inductancia (aro circular, radio R, conductor radio a) | `L = μ₀·R·(ln(8R/a) − 2)` |
| Reactancia | `X = 2π·f·L` |
| Capacidad de resonancia | `C = 1/(ω²·L) − C_parásita` |
| Resistencia de radiación | `R_rad = 320·π⁴·A²/λ⁴ ≈ 31 170·A²/λ⁴` |
| Resistencia superficial del cobre | `R_s = √(π·f·μ₀·ρ)` , ρ = 1,72·10⁻⁸ Ω·m |
| Resistencia de pérdidas | `R_p = R_s·P/(π·D_tubo) + R_uniones` |
| Eficiencia | `η = R_rad/(R_rad + R_p)` |
| Q cargado (adaptado) | `Q = X / (2·(R_rad+R_p))` |
| Ancho de banda (−3 dB) | `BW = f / Q` |
| Corriente en el loop | `I = √(P/(R_rad+R_p))` |
| **Tensión en el condensador** | **`V = I·X`** (rms), pico = V·√2 |
| Lazo de acoplo | `D_acoplo ≈ D_loop / 5` |

Un loop octogonal hecho con 8 tramos rectos y codos de 45° se comporta prácticamente
como un aro circular del mismo perímetro (error < 5 % en L).

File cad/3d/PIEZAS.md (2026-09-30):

# Piezas imprimibles

Parámetros comunes: capa 0,2 mm, boquilla 0,4, 4–5 perímetros. **Exterior: ASA o PETG** (el PLA se deforma al sol de Murcia).

| Pieza | Cant. | Material / ajustes | Vista |
|---|---|---|---|
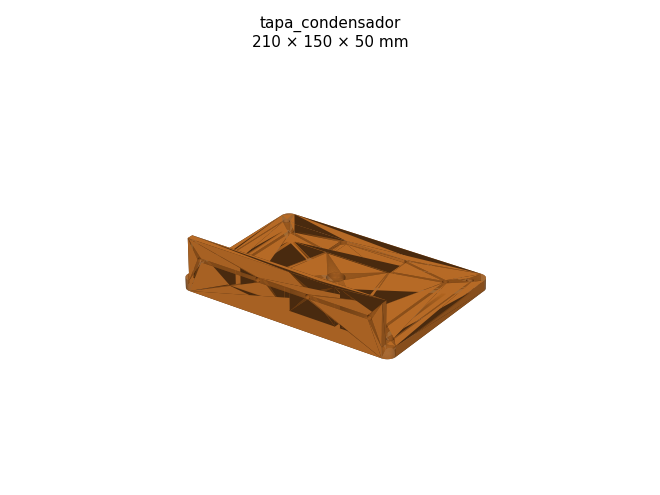
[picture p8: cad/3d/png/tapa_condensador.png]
| [`tapa_condensador.stl`](stl/tapa_condensador.stl) | 2 | PETG/ASA · 5 perímetros · 40 % gyroid · cara interior en la cama |  |
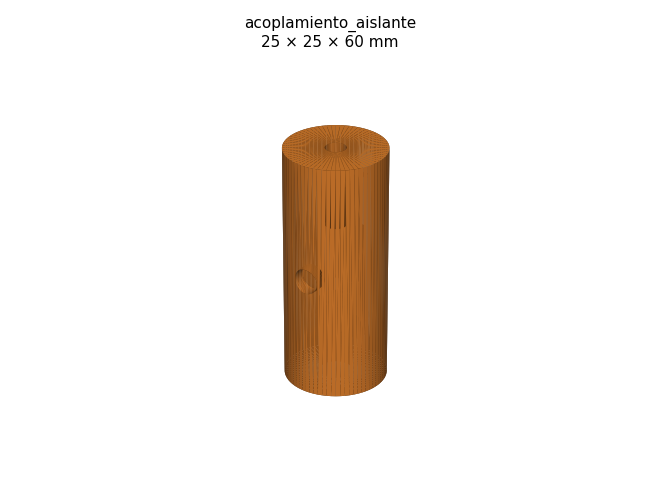
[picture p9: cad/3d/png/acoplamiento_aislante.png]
| [`acoplamiento_aislante.stl`](stl/acoplamiento_aislante.stl) | 1 | PETG · 100 % relleno · de pie |  |
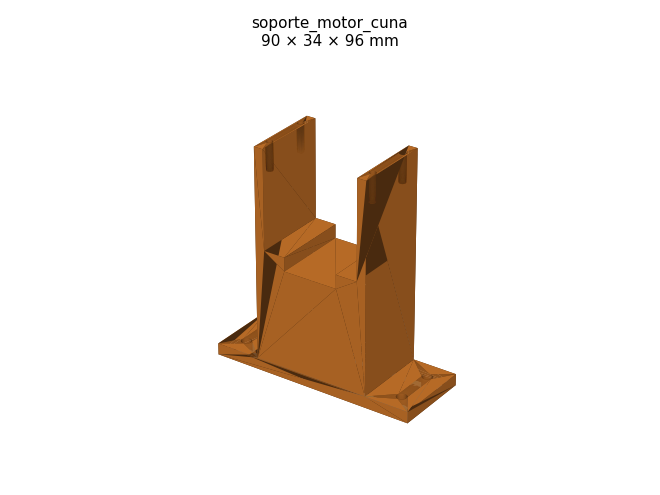
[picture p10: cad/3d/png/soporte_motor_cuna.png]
| [`soporte_motor_cuna.stl`](stl/soporte_motor_cuna.stl) | 1 | PETG · 30 % · sobre el pie |  |
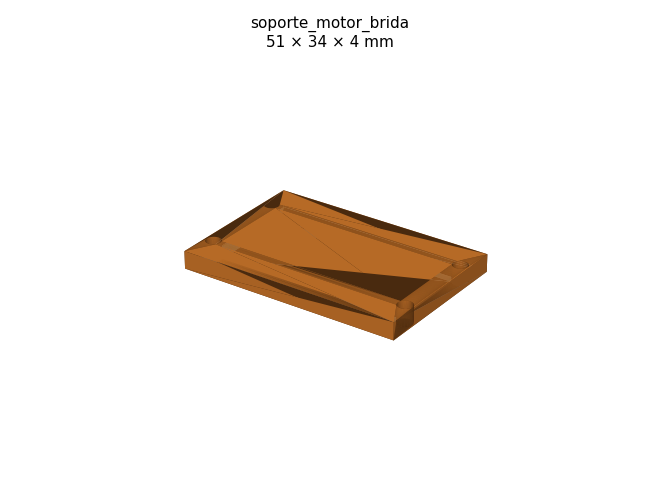
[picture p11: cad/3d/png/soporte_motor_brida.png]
| [`soporte_motor_brida.stl`](stl/soporte_motor_brida.stl) | 1 | PETG · 40 % |  |
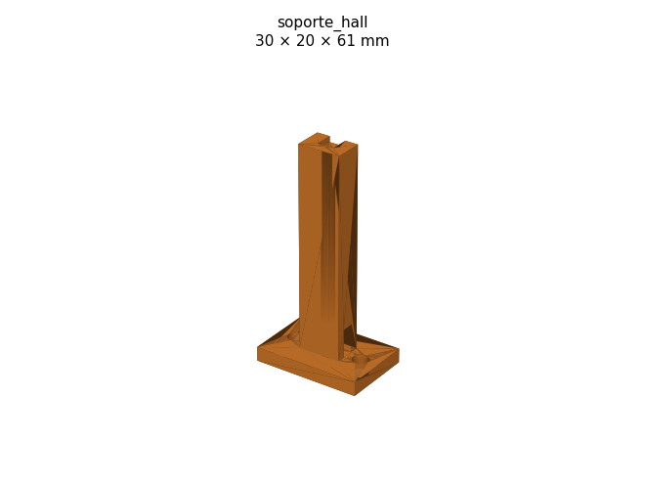
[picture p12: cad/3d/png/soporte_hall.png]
| [`soporte_hall.stl`](stl/soporte_hall.stl) | 1 | PETG · 40 % |  |
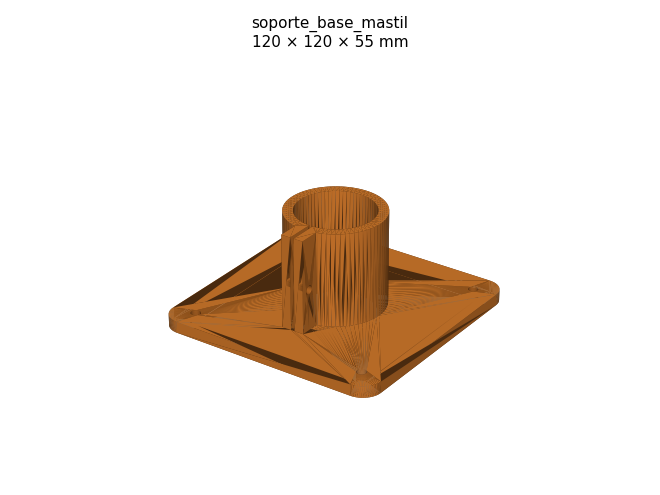
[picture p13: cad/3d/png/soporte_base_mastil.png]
| [`soporte_base_mastil.stl`](stl/soporte_base_mastil.stl) | 1 | ASA/PETG · 50 % · placa en la cama |  |
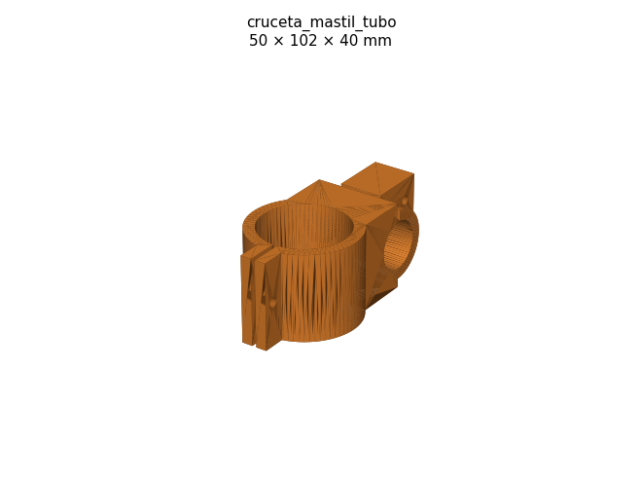
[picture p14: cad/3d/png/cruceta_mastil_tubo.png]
| [`cruceta_mastil_tubo.stl`](stl/cruceta_mastil_tubo.stl) | 1 | ASA/PETG · 50 % · soportes en el agujero del tubo |  |
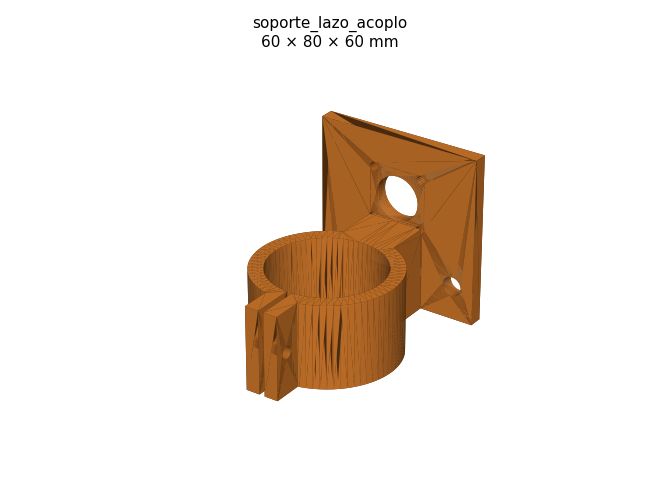
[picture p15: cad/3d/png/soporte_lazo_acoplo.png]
| [`soporte_lazo_acoplo.stl`](stl/soporte_lazo_acoplo.stl) | 1 | ASA/PETG · 50 % |  |
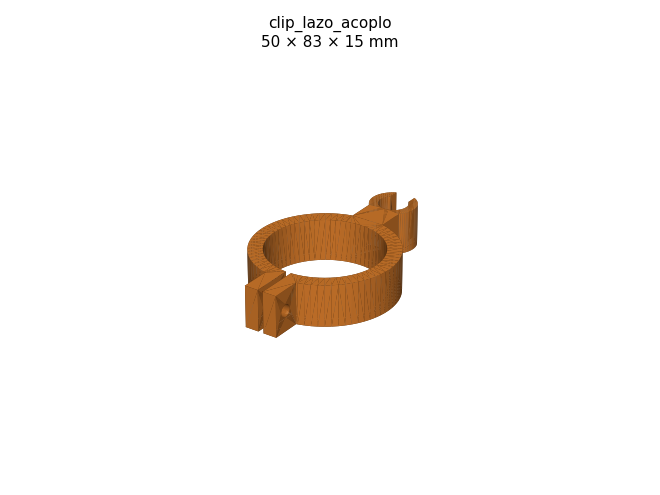
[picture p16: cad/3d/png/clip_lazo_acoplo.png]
| [`clip_lazo_acoplo.stl`](stl/clip_lazo_acoplo.stl) | 1 | ASA/PETG · 40 % (ajusta d_cable) |  |
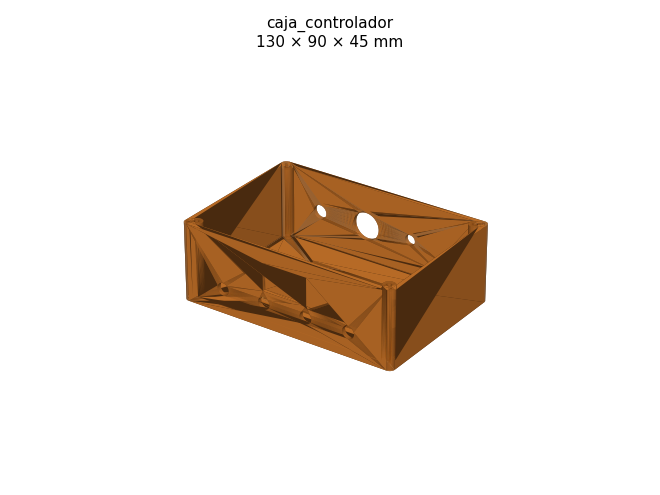
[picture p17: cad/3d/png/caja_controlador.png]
| [`caja_controlador.stl`](stl/caja_controlador.stl) | 1 | PLA/PETG · 20 % |  |
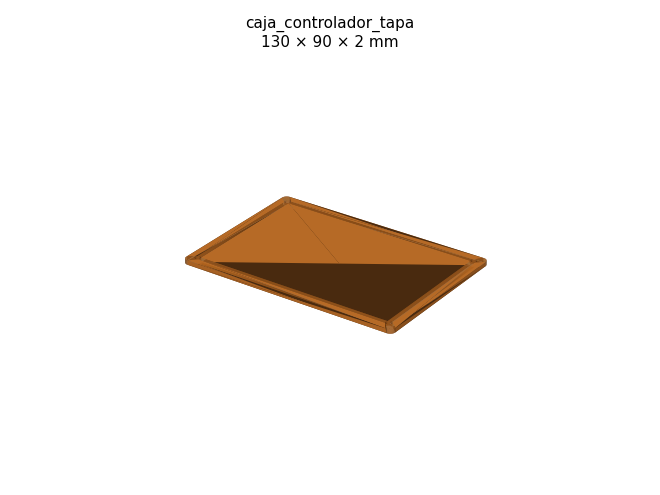
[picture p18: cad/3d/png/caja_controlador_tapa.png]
| [`caja_controlador_tapa.stl`](stl/caja_controlador_tapa.stl) | 1 | PLA/PETG · 20 % |  |
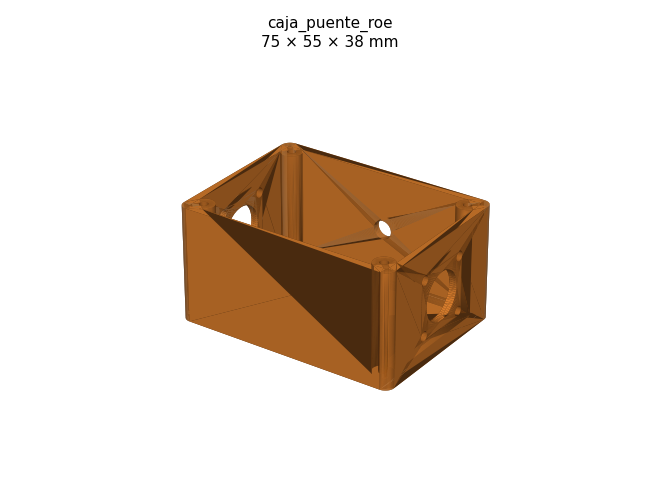
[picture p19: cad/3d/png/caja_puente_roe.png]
| [`caja_puente_roe.stl`](stl/caja_puente_roe.stl) | 1 | PLA/PETG · 20 % |  |
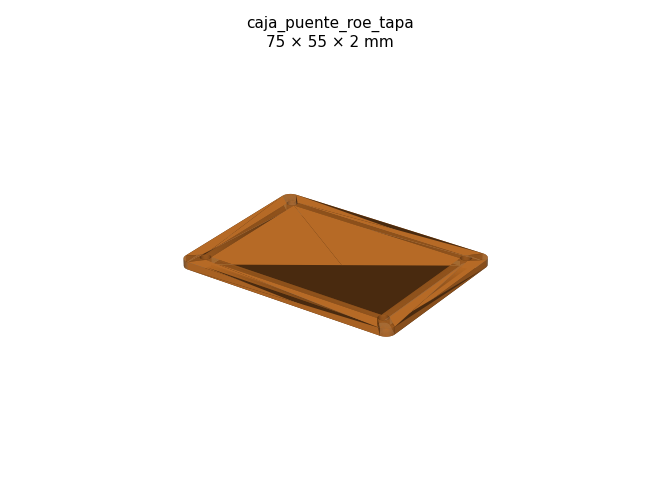
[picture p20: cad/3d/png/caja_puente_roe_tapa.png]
| [`caja_puente_roe_tapa.stl`](stl/caja_puente_roe_tapa.stl) | 1 | PLA/PETG · 20 % |  |

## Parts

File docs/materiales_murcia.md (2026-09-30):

# Dónde conseguir los materiales en Murcia

> Direcciones, horarios y precios cambian: llama antes. Los precios son orientativos (2026).
> Las cantidades exactas por versión están en [`resultados/lista_materiales.md`](../resultados/lista_materiales.md).

## 1. Placas de aluminio cortadas por láser (lo más importante)

Lleva en un pendrive (o manda por email) los ficheros **`cad/salida/rotor.dxf`** y
**`cad/salida/estator.dxf`**. Pide:

- **Aluminio 1 mm**, aleación EN AW-1050 o 5754 (vale cualquiera que tengan en stock; 5754 es más rígida).
- Cantidades: ver lista de materiales (+10 % de repuesto).
- **Desbarbado** (vibrado/lijado) de los cantos: en alta tensión cualquier rebaba es un punto de arco.
- Que **no** doblen ni marquen las placas: tienen que quedar planas.
- Orientativo: 1–2 € por pieza en series de 50–100; muchos talleres ponen el material.

| Taller | Zona | Web |
|---|---|---|
| Corte Láser García | Murcia | https://lasergarcia.es/ |
| Corte Láser JM (también metacrilato) | Murcia | https://cortelaserjm.com/ |
| GME Lasercut (corte y grabado) | Murcia | https://gmelasercut.es/ |
| Cortyple – corte de chapa a medida | Murcia | https://cortyple.com/ |
| Láser Molina | Molina de Segura | https://www.lasermolina.com/ |
| Plegados Nicolás – corte láser | Murcia | https://www.plegadosnicolas.es/corte-laser |
| Moralsa (almacén propio de chapa) | Región de Murcia | https://www.moralsa.com/ |
| TCI Cutting / Sidemur (aluminio y férricos) | Murcia | http://sidemur.es/productos/corte-de-chapa-en-laser/ |
| **Alternativa online**: LaserBoost (subes el DXF, te lo envían) | envío | https://www.laserboost.com/es/corte-laser-murcia/ |

Si solo consigues **acero inoxidable 1 mm**, también sirve (TA2WK lo ofrece), pero pesa ~3× y
tiene más resistencia; en la mariposa la corriente por placa es baja, así que las pérdidas son aceptables.

## 2. Tapas (placas finales) aislantes

Fichero **`cad/salida/tapa.dxf`**, 2 unidades, **policarbonato o metacrilato de 8–10 mm**
(el policarbonato aguanta mejor el sol y los golpes; si la antena va en exterior, mejor
policarbonato o PTFE). Alternativa: imprimir en **PETG/ASA** con 100 % de relleno.

- Corte Láser JM – taller de metacrilato: https://cortelaserjm.com/taller-metacrilato/
- Diseñato (metacrilato y policarbonato en Murcia): https://www.disenato.com/content/13-metacrilato-en-murcia
- GME Lasercut: https://gmelasercut.es/
- Impresión 3D: pregunta en el Radio Club Región de Murcia o en makerspaces locales.

## 3. Tornillería inoxidable M5

Varilla roscada **M5 inox A2 (DIN 975)** en barras de 1 m, **tuercas DIN 934 M5** (altura 4 mm) y
**arandelas DIN 125 M5** (espesor 1 mm), **siempre inox** (no zincado: se oxida y el óxido provoca arcos).

- Obramat Murcia (ex-Bricomart): https://www.obramat.es/almacenes/obramat-murcia.html
- Leroy Merlin Murcia y ferreterías / suministros industriales de la zona (compra por cajas de 100: sale mucho más barato).
- Suministro industrial online con base en Murcia: https://todoparalaindustria.com/collections/suministro-industrial

**Receta de separadores** (evita tener que cortar tubo con precisión):

| Hueco | Separador | Montaje |
|---|---|---|
| 3 mm | 7 mm | 1 tuerca + 3 arandelas |
| 4 mm | 9 mm | 2 tuercas + 1 arandela |
| 5 mm | 11 mm | 2 tuercas + 3 arandelas |
| 6 mm | 13 mm | 3 tuercas + 1 arandela |

Mide un lote de tuercas con el calibre: si salen de 3,8 mm en vez de 4,0 compensa con arandelas.
Alternativa más limpia: **tubo de aluminio 8×1 mm** cortado a medida (tornero o taller de aluminio).

## 4. Tubo de cobre para el loop

- **Tubo de cobre 22 mm** (barra 2,5 m, rígido) + **8 codos de 45°** de soldar para hacer un octógono de 1 m:
  Obramat Murcia (barra 22 mm 2,5 m: https://www.obramat.es/barra-cobre-o22mm-2-5m-10424911.html),
  Leroy Merlin, BigMat, almacenes de fontanería.
- Para el octógono de Ø 1 m necesitas **3,14 m** de perímetro → 8 tramos de ≈ 39 cm → **2 barras de 2,5 m**.
- Alternativa: **tubo de cobre recocido** en rollo (se curva a mano en círculo), en almacenes de climatización.
- Soldadura: **estaño-plata (soldadura blanda de fontanería) o mejor soldadura fuerte (plata 15–40 %)**
  con soplete. Las uniones son la principal fuente de pérdidas.

## 5. Electrónica / RF

- **Electrónica Llorga** (Murcia): https://electronicallorga.com/ — conectores PL-259/SO-239 o N, coaxial RG-213/RG-58,
  terminales, termorretráctil, núcleos de ferrita (choke), motorreductor 12 V.
- Murcia Electrónica – tienda de componentes: https://www.murciaelectronica.com/category/tienda-de-componentes-electronicos/
- Listados de tiendas: https://murcia10.es/tienda-componentes-electronicos-murcia/
- **Reductora planetaria 6:1 / dial vernier**: no es habitual en tiendas físicas; se compra online
  (eBay, AliExpress, Oren Elliott Products, MGS4U, enlaces del artículo de TA2WK) o de segunda mano
  en el **Merca Radio Región de Murcia**.

## 6. Comunidad local (muy recomendable)

- **Radio Club Región de Murcia – EA5RCZ**: https://ea5rcz.es/ (organizan el Merca Radio, donde se
  encuentran condensadores de vacío, reductoras, analizadores de antena…).
- URE – Secciones: https://www.ure.es/secciones/

Con ellos puedes conseguir prestado un **medidor LCR** (para medir Cmin/Cmax) y un
**analizador de antenas** (NanoVNA, RigExpert) para ajustar el loop.

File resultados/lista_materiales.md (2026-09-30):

# Lista de materiales del condensador

Cantidades por versión. Los separadores de tuerca+arandela son la opción más fácil de comprar en Murcia; el tubo de aluminio (Ø 8×1 mm) cortado a medida queda más limpio.

| Pieza | Especificación | A · QRP / portable | B · 50 W | C · 100 W |
|---|---|---|---|---|
| Placa rotor (corte láser) | Aluminio 1 mm (EN AW-1050/5754), rotor.dxf | 15 | 21 | 26 |
| Placa estátor (corte láser) | Aluminio 1 mm, estator.dxf | 32 | 44 | 54 |
| Placas de repuesto (+10 %) |  | 5 | 7 | 8 |
| Superficie de aluminio neta | cm² (pide chapa 1000×500 mm o que el taller ponga el material) | 3922 | 5431 | 6689 |
| Tapas / placas finales | Policarbonato o metacrilato 8–10 mm, 240×240, tapa.dxf | 2 | 2 | 2 |
| Varilla roscada M5 estátor | Inox A2 DIN 975, 4 tramos de (mm) | 4 × 196 | 4 × 280 | 4 × 377 |
| Eje del rotor | Varilla M5 inox (o eje liso de 5 mm), mm | 1 × 266 | 1 × 350 | 1 × 447 |
| Separadores estátor | de 7/9/11/13 mm según versión (ver receta) | 60 | 84 | 104 |
| Separadores rotor | misma longitud, en el eje central | 14 | 20 | 25 |
| Tuercas M5 DIN 934 inox | incluye las de los separadores + 20 de fijación | 94 | 228 | 278 |
| Arandelas M5 DIN 125 inox | incluye separadores + 20 | 242 | 124 | 407 |
| Collarines / anillos de bloqueo 5 mm | para fijar el rotor en el eje | 2 | 2 | 2 |
| Tirantes entre tapas | Varilla M6 nylon o fibra de vidrio + tuercas nylon | 4 | 4 | 4 |
| Rodamiento 625ZZ (5×16×5 mm) | para el eje M5 en las tapas | 2 | 2 | 2 |
| Acoplamiento aislante | manguito de nylon/PVC o acoplador flexible + tramo de varilla de fibra | 1 | 1 | 1 |
| Reductora | planetaria 6:1 (manual) o motorreductor 12 V 1–5 rpm | 1 | 1 | 1 |
| Pletina/malla de cobre | cinta 20–25 mm o malla de coaxial para unir estátores al loop | 2 × 20 cm | 2 × 20 cm | 2 × 20 cm |
| Terminales de cobre | para crimpar 10–16 mm², ojal M5 | 4 | 4 | 4 |

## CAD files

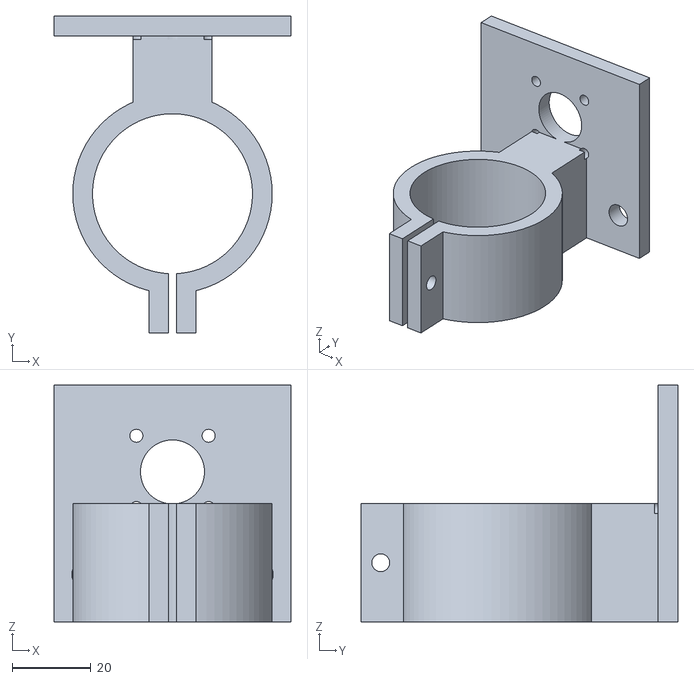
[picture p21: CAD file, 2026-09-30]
cad/3d/stl/soporte_lazo_acoplo.stl
60.0 x 80.2 x 60.0

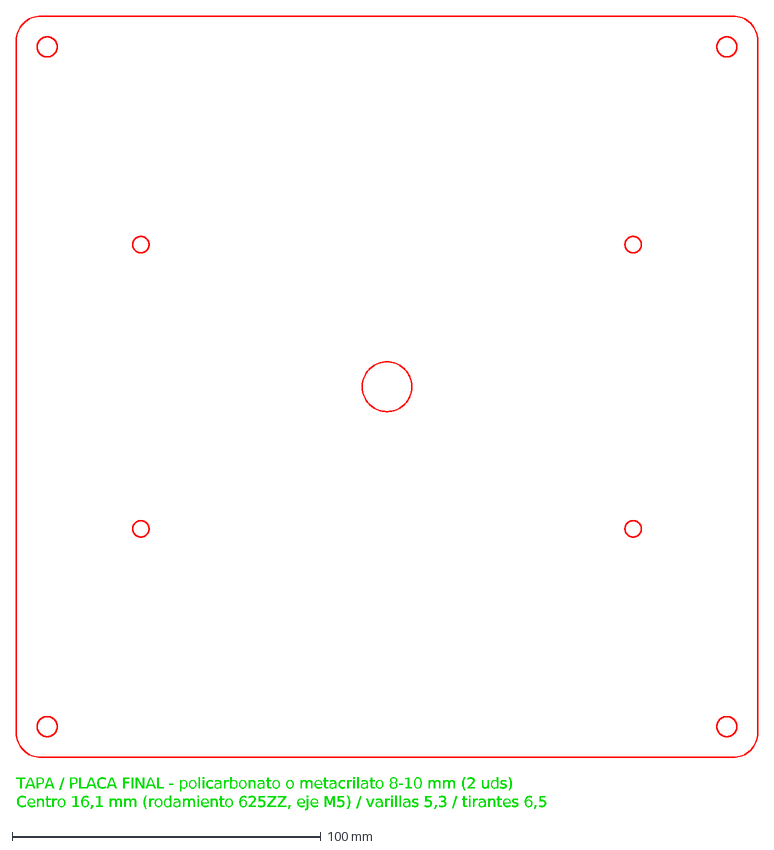
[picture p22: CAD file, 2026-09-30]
cad/salida/tapa.dxf
TAPA / PLACA FINAL - policarbonato o metacrilato 8-10 mm (2 uds)
Centro 16,1 mm (rodamiento 625ZZ, eje M5) / varillas 5,3 / tirantes 6,5

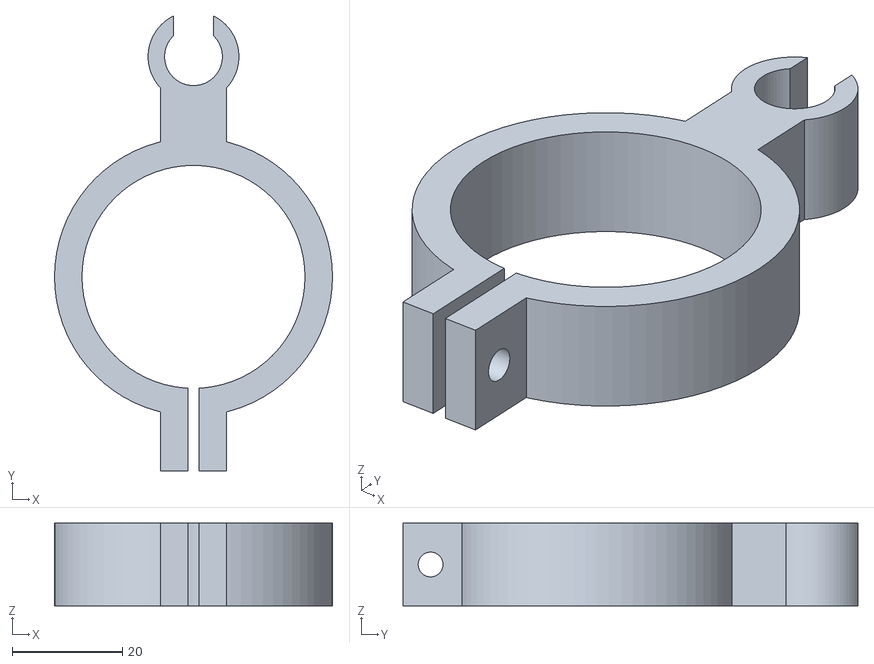
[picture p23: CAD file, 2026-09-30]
cad/3d/stl/clip_lazo_acoplo.stl
50.5 x 82.6 x 15.0

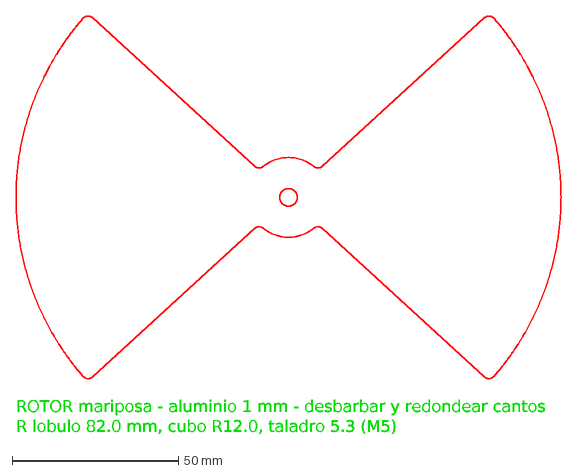
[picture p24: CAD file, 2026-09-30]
cad/salida/rotor.dxf
ROTOR mariposa - aluminio 1 mm - desbarbar y redondear cantos
R lobulo 82.0 mm, cubo R12.0, taladro 5.3 (M5)

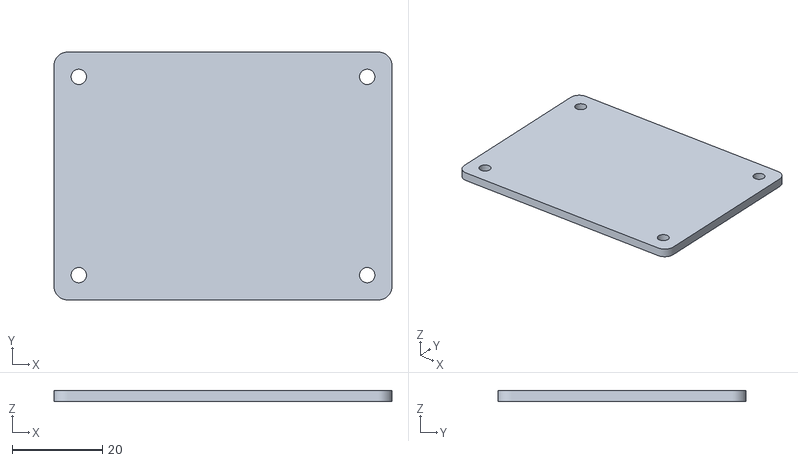
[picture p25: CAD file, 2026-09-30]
cad/3d/stl/caja_puente_roe_tapa.stl
75.0 x 55.0 x 2.50

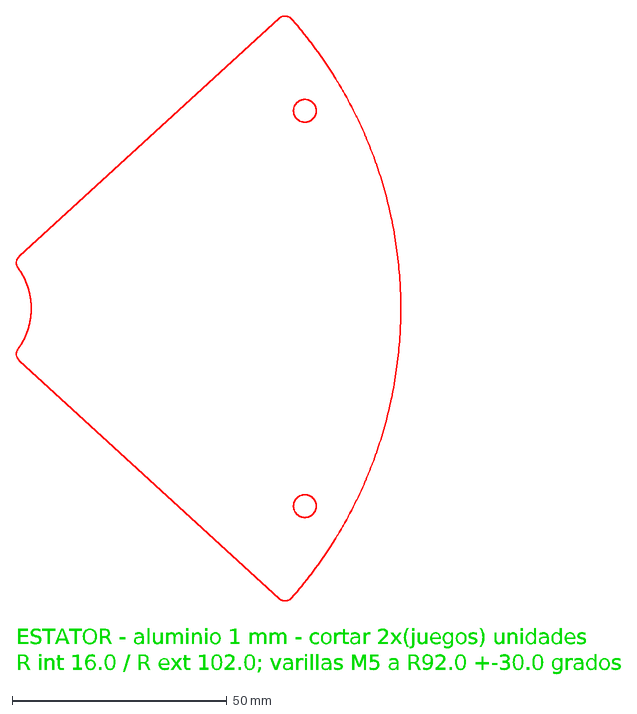
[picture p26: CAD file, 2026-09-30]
cad/salida/estator.dxf
ESTATOR - aluminio 1 mm - cortar 2x(juegos) unidades
R int 16.0 / R ext 102.0; varillas M5 a R92.0 +-30.0 grados

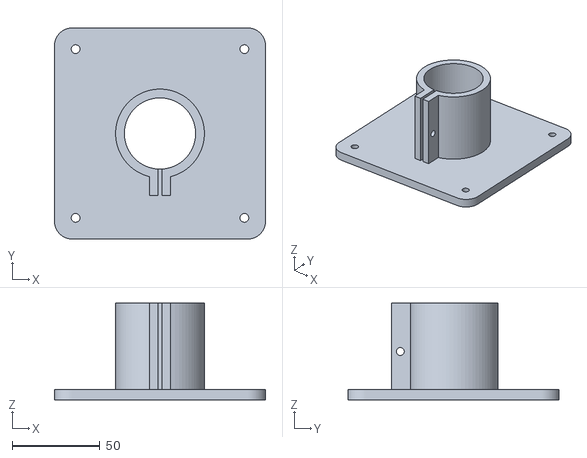
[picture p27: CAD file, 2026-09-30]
cad/3d/stl/soporte_base_mastil.stl
120.0 x 120.0 x 55.0

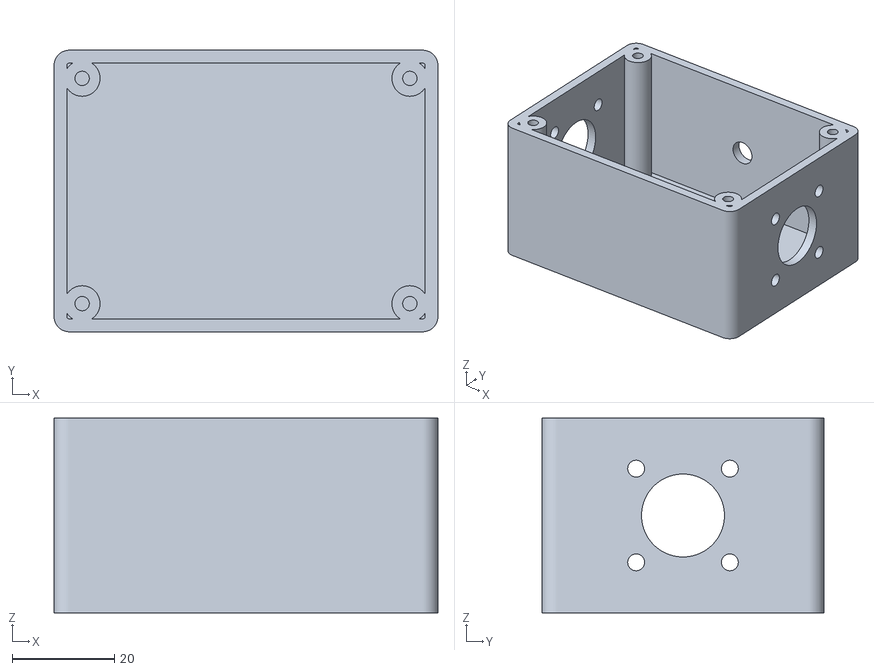
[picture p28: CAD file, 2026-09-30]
cad/3d/stl/caja_puente_roe.stl
75.0 x 55.0 x 38.0

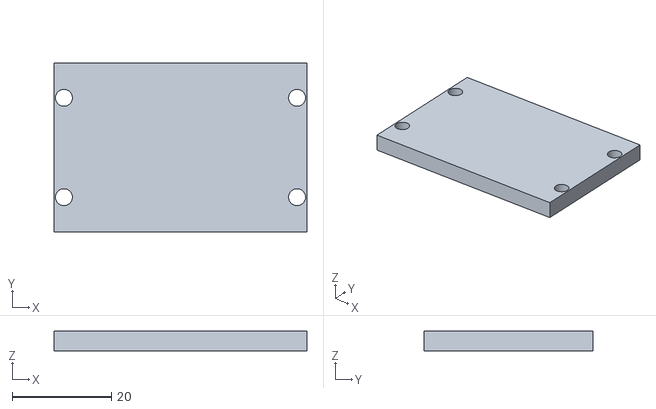
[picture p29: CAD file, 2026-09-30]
cad/3d/stl/soporte_motor_brida.stl
50.9 x 34.0 x 4.00

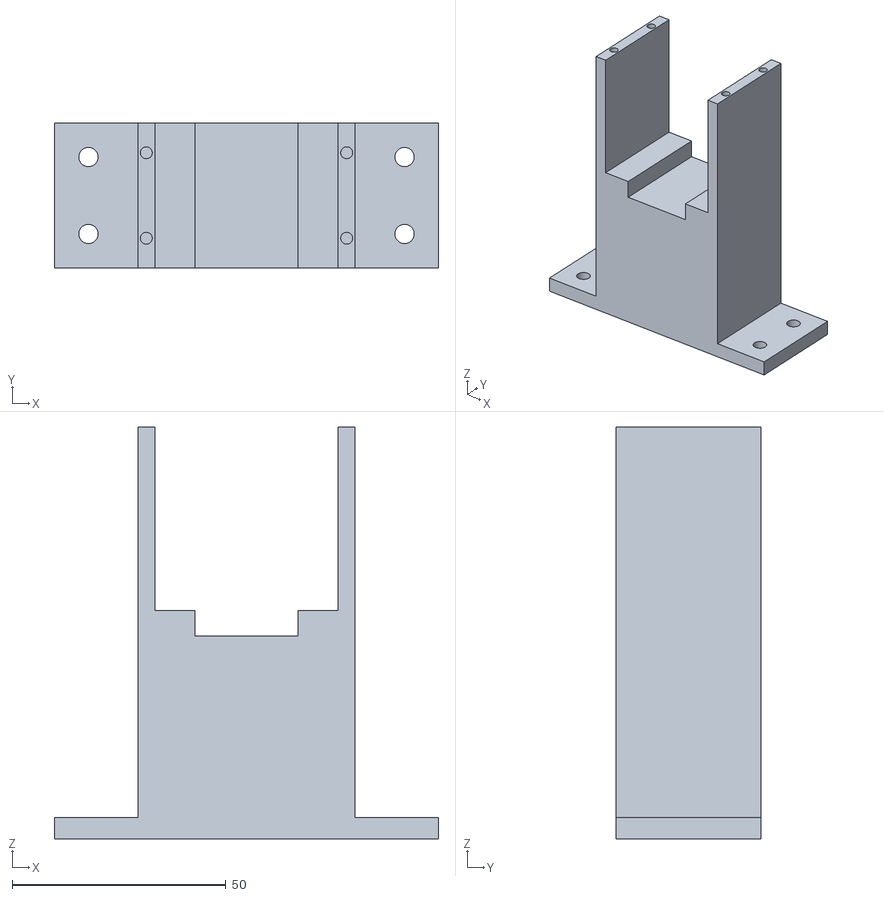
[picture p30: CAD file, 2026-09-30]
cad/3d/stl/soporte_motor_cuna.stl
90.0 x 34.0 x 96.5

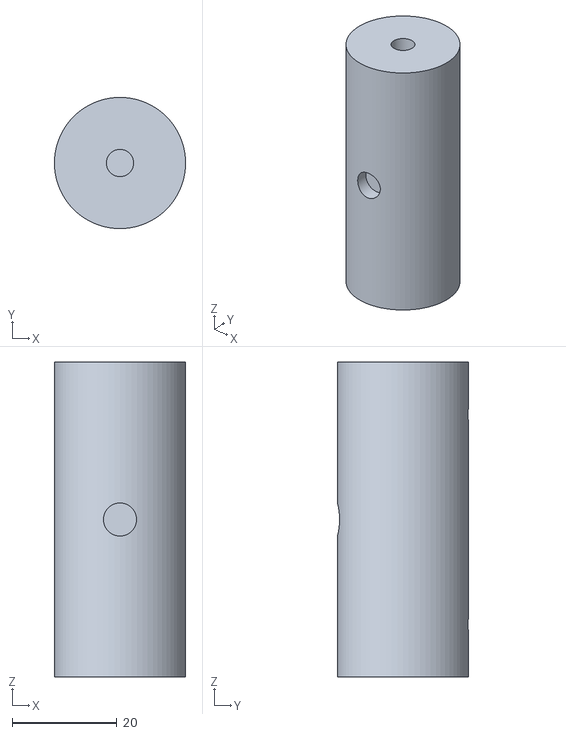
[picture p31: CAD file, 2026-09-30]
cad/3d/stl/acoplamiento_aislante.stl
25.0 x 25.0 x 60.0

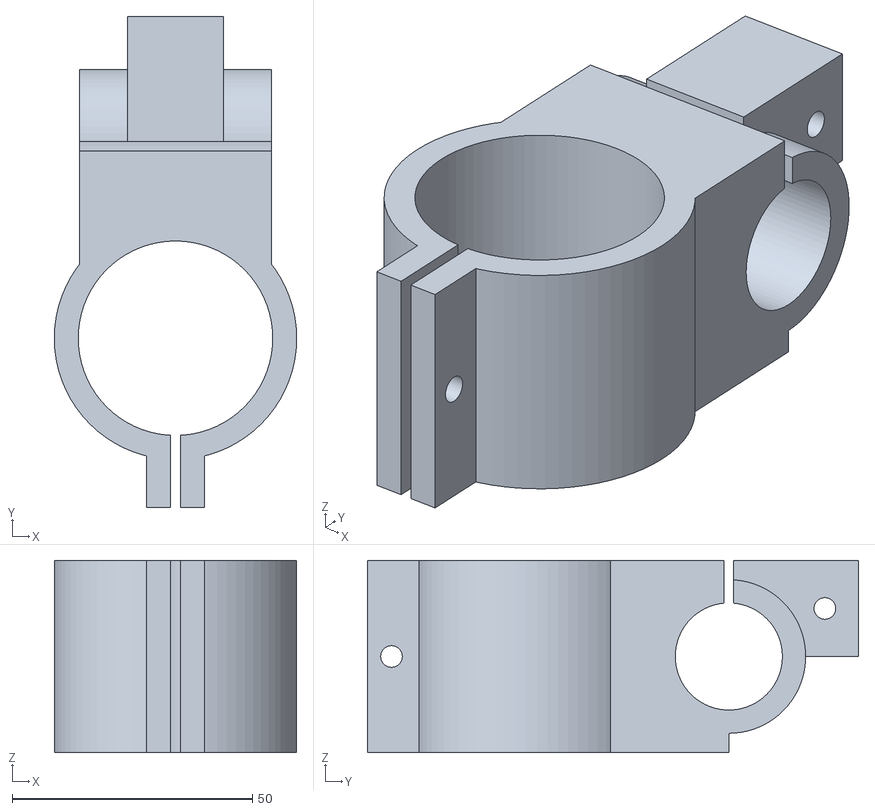
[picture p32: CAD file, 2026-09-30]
cad/3d/stl/cruceta_mastil_tubo.stl
50.5 x 102.2 x 40.0

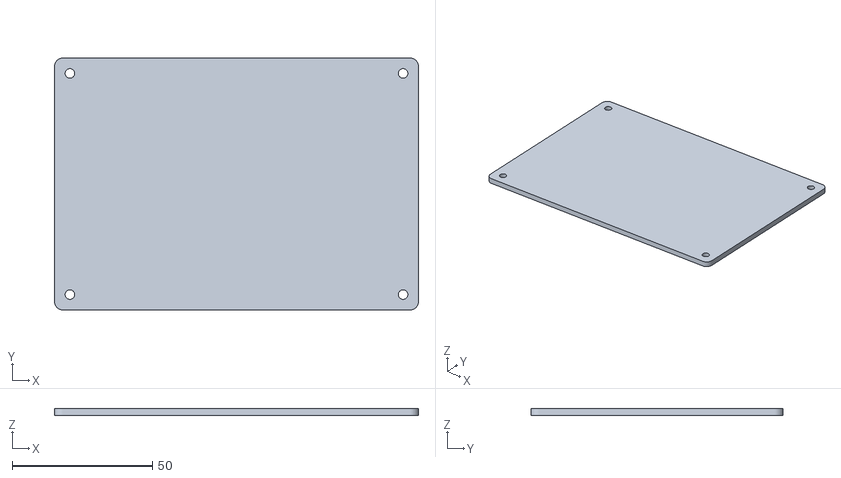
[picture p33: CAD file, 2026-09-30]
cad/3d/stl/caja_controlador_tapa.stl
130.0 x 90.0 x 2.50

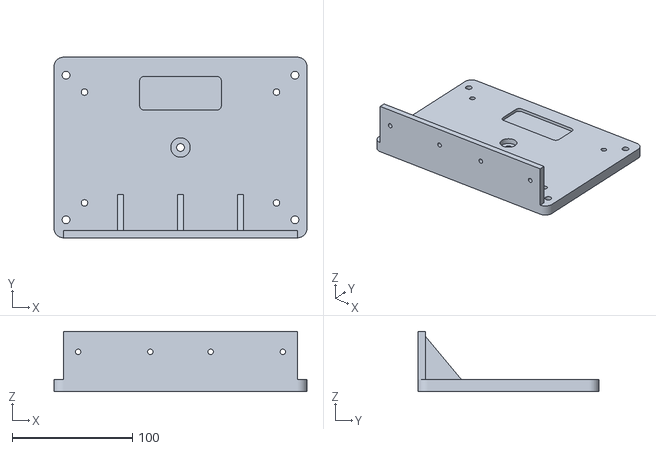
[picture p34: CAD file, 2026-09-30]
cad/3d/stl/tapa_condensador.stl
210.0 x 150.0 x 50.0

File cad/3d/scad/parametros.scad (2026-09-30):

// GENERADO por cad/generar_3d.py (versión B). No editar a mano.
r_varillas = 92.0;
ang_varillas = 30;
r_rotor = 82.0;
r_stator_ext = 102.0;
gap = 4;
separador = 9;
juegos = 22;
longitud_pack = 190;
d_eje = 5;
d_eje_motor = 8;
rodamiento_d = 16.2;
rodamiento_h = 5.2;
altura_eje = 75;
d_mastil = 40;
d_tubo = 22;
separacion_loop = 40;

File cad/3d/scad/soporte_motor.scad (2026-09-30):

// CUNA DEL MOTOR NEMA17 (con o sin reductora planetaria). Imprimir 1 + 1 brida superior.
// El eje queda a la misma altura que el eje del condensador (altura_eje).
include <parametros.scad>
include <comun.scad>
m = 42.3 + 0.6;    // cuerpo NEMA17 + holgura
p = 4; L = 34;     // pared y longitud de agarre
suelo = altura_eje - m / 2;
parte = "cuna";    // "cuna" o "brida"
if (parte == "cuna") {
  difference() {
    union() {
      translate([-45, 0, 0]) cube([90, L, 5]);                                   // pie
      translate([-m/2 - p, 0, 0]) cube([m + 2*p, L, suelo + m]);
    }
    translate([-m/2, -1, suelo]) cube([m, L + 2, m + 1]);                         // hueco del motor
    translate([-12, -1, suelo - 6]) cube([24, L + 2, 7]);                          // paso de cables
    for (x = [-37, 37]) for (y = [8, L - 8]) translate([x, y, -1]) cylinder(d = 4.5, h = 7);
    for (x = [-(m/2 + p/2), m/2 + p/2]) for (y = [7, L - 7])
      translate([x, y, suelo + m - 12]) cylinder(d = 2.8, h = 13);                 // M3 rosca en plástico
  }
} else {
  difference() {
    translate([-m/2 - p, 0, 0]) cube([m + 2*p, L, 4]);
    for (x = [-(m/2 + p/2), m/2 + p/2]) for (y = [7, L - 7]) translate([x, y, -1]) cylinder(d = 3.4, h = 6);
  }
}

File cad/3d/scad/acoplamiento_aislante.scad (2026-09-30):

// ACOPLAMIENTO AISLANTE motor -> eje del rotor (imprimir 1, PETG 100 % relleno)
// Lado A: eje de salida de la reductora (Ø8). Lado B: eje del rotor M5.
// 20 mm de plástico macizo en medio = aislamiento. Alojamiento radial para imán 6x3 mm (home).
include <parametros.scad>
include <comun.scad>
D = 25; L = 60; prof = 20;
module prisionero(z, rb) {   // tornillo M3 radial + hueco para tuerca
  translate([0, 0, z]) rotate([-90, 0, 0]) cylinder(d = 3.2, h = D);
  translate([-5.8/2, rb + 1.5, z - 3]) cube([5.8, 2.8, 30]);
}
difference() {
  cylinder(d = D, h = L);
  translate([0, 0, -1]) cylinder(d = d_eje_motor + 0.2, h = prof + 1);     // motor
  translate([0, 0, L - prof]) cylinder(d = d_eje + 0.2, h = prof + 1);     // rotor
  prisionero(prof / 2, d_eje_motor / 2);
  translate([0, 0, L]) mirror([0, 0, 1]) prisionero(prof / 2, d_eje / 2);
  translate([0, 0, L / 2]) rotate([90, 0, 0]) translate([0, 0, D/2 - 3.3]) cylinder(d = 6.3, h = 4); // imán
}

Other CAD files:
cad/3d/stl/soporte_hall.stl
cad/3d/stl/caja_controlador.stl
cad/3d/scad/cajas.scad
cad/3d/scad/clip_lazo_acoplo.scad
cad/3d/scad/comun.scad
cad/3d/scad/cruceta_mastil_tubo.scad
cad/3d/scad/soporte_base_mastil.scad
cad/3d/scad/soporte_hall.scad
cad/3d/scad/soporte_lazo_acoplo.scad
cad/3d/scad/tapa_condensador.scad

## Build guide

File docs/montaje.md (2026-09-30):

# Montaje paso a paso

Basado en el procedimiento de TA2WK, adaptado a las piezas de este repositorio.
Ejemplo con la **versión B (hueco 4 mm, 22 juegos, separador 9 mm)**; para otra versión
cambia solo el separador y el número de placas.

## Herramientas

Calibre (pie de rey), llaves de 8 mm (M5) ×2, llave de tubo de 8 mm, taladro de columna
(si hay que repasar agujeros), broca 5,5 mm, lima fina y lija 400–600, sierra para metal o
cortatubos (loop), soplete + soldadura (loop), medidor LCR, analizador de antena o NanoVNA,
guantes (los cantos del aluminio cortan).

## 1. Preparar las placas

1. Comprueba que todas las placas están **planas** (apóyalas sobre un cristal).
2. **Desbarba** los cantos: lija 400 → 600 hasta que al pasar el dedo no notes nada. Redondea las esquinas.
3. Repasa los agujeros con broca 5,5 mm si el M5 entra justo.
4. Limpia con alcohol isopropílico. No toques más las caras con los dedos.

## 2. Montar los dos grupos de estátor

1. Corta **4 varillas M5** a la longitud de la lista de materiales.
2. En cada varilla pon una tuerca de tope + arandela a la altura de la primera tapa.
3. Monta **dos varillas por lado** (A = derecha, B = izquierda) atravesando la tapa trasera.
4. Apila: *placa de estátor → separador (2 tuercas + 1 arandela = 9 mm) → placa de estátor →…*
   hasta tener **22 placas por lado**. Aprieta cada separador ligeramente para que la placa quede
   perpendicular. Comprueba con el calibre que la distancia entre placas es **9,0 mm ± 0,2**.
5. El estátor B es la **misma pieza girada 180°**.

## 3. Montar el rotor

1. En el eje central (varilla M5 o eje de 8 mm) coloca un collarín, la primera placa de rotor y
   separadores de 9 mm entre placas de rotor (**21 placas**).
2. Cierra con otro collarín/doble tuerca. Todas las placas de rotor deben quedar **alineadas
   angularmente** (usa una regla apoyada en los lóbulos antes de apretar).
3. Introduce el rotor entre los estátores con el rotor girado 90° (posición de Cmin) y desliza el eje
   por los rodamientos/casquillos de las tapas.

## 4. Centrado (el paso crítico)

1. Gira el rotor a Cmax: **cada placa de rotor tiene que quedar justo en medio de dos placas de estátor**
   (4 mm a cada lado). Ajusta la posición axial del rotor con las tuercas del eje.
2. Si un extremo toca y el otro no, las placas no son paralelas: corrige con arandelas.
3. Gira 360° a mano: no debe rozar en ningún punto. Mira contra una luz: se debe ver una ranura
   uniforme.
4. Coloca los 4 tirantes aislantes (M6 nylon o fibra) entre tapas y aprieta.

## 5. Pruebas eléctricas

1. **Continuidad**: entre A y B **no** debe haber continuidad en ninguna posición; entre rotor y A/B tampoco.
2. **LCR** entre A y B: anota Cmin (rotor a 90°) y Cmax (0°). Compara con `resultados/variantes.md`.
3. Si tienes acceso a un medidor de aislamiento (megger 1–5 kV) pruébalo; si no, empieza transmitiendo
   con **5–10 W** y sube poco a poco escuchando si hay chisporroteo.

## 6. Accionamiento

- El rotor está **a potencial de RF** (unos kV respecto a tierra en el peor caso): el eje debe unirse a la
  reductora/motor mediante un **acoplamiento aislante** (tramo de varilla de fibra de vidrio o nylon de
  10 cm mínimo).
- Manual: **reductora planetaria 6:1** o **dial vernier** (180° de recorrido, suficiente porque la
  mariposa va de Cmax a Cmin en 90°).
- Remoto con autoajuste (recomendado): NEMA17 + reductora 27:1 + ESP32, piezas impresas y firmware de este
  repositorio. Ver [guía paso a paso](guia_paso_a_paso.md).

## 7. Conexión al loop

- Une cada grupo de estátor a un extremo del loop con **pletina de cobre de 20–25 mm** o malla ancha,
  lo **más corta posible** (cada mΩ cuenta: con 100 W circulan 25–50 A).
- Terminales de ojal M5 atornillados en las varillas del estátor con arandela y tuerca inox, o mejor
  soldar una lengüeta de cobre al tubo.
- El condensador va en la **parte de arriba** del loop; el lazo de acoplo (Ø D/5) en la de abajo, en el
  plano del loop.

## 8. Ajuste

1. Conecta NanoVNA/analizador al lazo de acoplo.
2. Gira el condensador hasta ver el "pico" de resonancia en la banda.
3. Deforma ligeramente el lazo de acoplo (más ovalado / más redondo, o acércalo/aléjalo del tubo)
   hasta conseguir **ROE < 1,5**.
4. Recuerda: el ancho de banda es estrechísimo (ver tabla del loop); cada cambio de más de unos kHz
   exige retocar el condensador.

## Seguridad

- **Alta tensión RF**: 3–6 kV con 100 W. Quemaduras de RF graves. Nunca toques loop ni condensador
  transmitiendo.
- Campo magnético intenso cerca del loop: mantén **≥ 3 m** de distancia de personas en transmisión a 100 W
  (consulta la normativa de exposición de radioaficionados en España, Orden CTE/23/2002 y RD 1066/2001).
- Protege el condensador de la lluvia y el polvo (caja de PVC/policarbonato): la humedad reduce
  la tensión de ruptura.

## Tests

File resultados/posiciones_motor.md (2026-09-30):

# Posiciones del motor por banda (versión B, loop Ø 1.0 m, tubo 22 mm)

Motor 200 pasos × 16 micropasos × reductora 27:1 = **240 pasos/grado**. Home (sensor Hall) = Cmin. Recorrido útil 0–90° = 0–21600 pasos.
Modelo lineal C(θ): sin solape los primeros 5°, después C crece linealmente hasta Cmax a 90°.

| Banda | f (kHz) | C (pF) | Ángulo desde Cmin | Paso preset | kHz por paso | Ancho de banda (kHz) |
|---|---|---|---|---|---|---|
| 80m | 3650 | 774 | fuera de rango | — | — | — |
| 60m | 5360 | 358 | fuera de rango | — | — | — |
| 40m | 7100 | 203 | 81.5° | 19554 | 0.172 | 5.5 |
| 30m | 10120 | 98 | 37.8° | 9064 | 0.498 | 8.8 |
| 20m | 14200 | 49 | 16.9° | 4061 | 1.374 | 19.0 |
| 17m | 18120 | 29 | 8.6° | 2068 | 2.855 | 40.6 |
| 15m | 21200 | 20 | 5.1° | 1214 | 4.570 | 70.3 |
| 12m | 24940 | 14 | fuera de rango | — | — | — |
| 10m | 28500 | 10 | fuera de rango | — | — | — |

Los presets son un **punto de partida**: el autoajuste busca el mínimo de ROE alrededor de ellos y guarda la posición real aprendida en la memoria del ESP32.

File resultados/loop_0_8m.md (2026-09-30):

# Loop magnético Ø 0.8 m – 22 mm – 100 W

Loop circular (u octogonal equivalente) de **0.8 m de diámetro** (perímetro 2.51 m) en tubo de cobre de **22 mm**. Capacidad parásita estimada 2.1 pF (ya restada). Resistencia extra de uniones/soldaduras 5 mΩ. Lazo de acoplo recomendado: Ø 16 cm.

⚠️ La tensión en el condensador es la de un loop perfectamente adaptado: con 100 W aparecen varios kV. No toques el loop transmitiendo.

| Banda | f (MHz) | L (µH) | C necesaria (pF) | R rad (mΩ) | R pérd (mΩ) | Eficiencia | Q cargado | Ancho banda (kHz) | I loop (A) | V cond @100 W (V rms) | V pico |
|---|---|---|---|---|---|---|---|---|---|---|---|
| 80 m | 3.65 | 1.85 | 1028 | 0.17 | 23.1 | 0.7 % (-21.3 dB) | 910 | 4.0 | 65.5 | 2775 | 3925 |
| 60 m | 5.36 | 1.85 | 475 | 0.80 | 26.9 | 2.9 % (-15.4 dB) | 1121 | 4.8 | 60.0 | 3733 | 5279 |
| 40 m | 7.1 | 1.85 | 270 | 2.48 | 30.2 | 7.6 % (-11.2 dB) | 1258 | 5.6 | 55.3 | 4553 | 6439 |
| 30 m | 10.12 | 1.85 | 132 | 10.23 | 35.1 | 22.5 % (-6.5 dB) | 1294 | 7.8 | 46.9 | 5511 | 7794 |
| 20 m | 14.2 | 1.85 | 66 | 39.64 | 40.7 | 49.3 % (-3.1 dB) | 1025 | 13.9 | 35.3 | 5811 | 8218 |
| 17 m | 18.12 | 1.85 | 40 | 105.11 | 45.3 | 69.9 % (-1.6 dB) | 699 | 25.9 | 25.8 | 5419 | 7664 |
| 15 m | 21.2 | 1.85 | 28 | 196.95 | 48.6 | 80.2 % (-1.0 dB) | 501 | 42.3 | 20.2 | 4963 | 7018 |
| 12 m | 24.94 | 1.85 | 20 | 377.22 | 52.3 | 87.8 % (-0.6 dB) | 337 | 74.1 | 15.3 | 4414 | 6243 |
| 10 m | 28.5 | 1.85 | 15 | 643.26 | 55.6 | 92.0 % (-0.4 dB) | 237 | 120.5 | 12.0 | 3955 | 5593 |

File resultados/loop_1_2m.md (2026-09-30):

# Loop magnético Ø 1.2 m – 22 mm – 100 W

Loop circular (u octogonal equivalente) de **1.2 m de diámetro** (perímetro 3.77 m) en tubo de cobre de **22 mm**. Capacidad parásita estimada 3.1 pF (ya restada). Resistencia extra de uniones/soldaduras 5 mΩ. Lazo de acoplo recomendado: Ø 24 cm.

⚠️ La tensión en el condensador es la de un loop perfectamente adaptado: con 100 W aparecen varios kV. No toques el loop transmitiendo.

| Banda | f (MHz) | L (µH) | C necesaria (pF) | R rad (mΩ) | R pérd (mΩ) | Eficiencia | Q cargado | Ancho banda (kHz) | I loop (A) | V cond @100 W (V rms) | V pico |
|---|---|---|---|---|---|---|---|---|---|---|---|
| 80 m | 3.65 | 3.08 | 615 | 0.88 | 32.2 | 2.7 % (-15.8 dB) | 1068 | 3.4 | 55.0 | 3880 | 5488 |
| 60 m | 5.36 | 3.08 | 284 | 4.07 | 37.9 | 9.7 % (-10.1 dB) | 1233 | 4.3 | 48.8 | 5054 | 7148 |
| 40 m | 7.1 | 3.08 | 160 | 12.54 | 42.9 | 22.6 % (-6.5 dB) | 1238 | 5.7 | 42.5 | 5827 | 8241 |
| 30 m | 10.12 | 3.08 | 77 | 51.77 | 50.2 | 50.8 % (-2.9 dB) | 959 | 10.6 | 31.3 | 6123 | 8659 |
| 20 m | 14.2 | 3.08 | 38 | 200.69 | 58.6 | 77.4 % (-1.1 dB) | 529 | 26.8 | 19.6 | 5388 | 7620 |
| 17 m | 18.12 | 3.08 | 22 | 532.11 | 65.5 | 89.0 % (-0.5 dB) | 293 | 61.9 | 12.9 | 4529 | 6405 |
| 15 m | 21.2 | 3.08 | 15 | 997.05 | 70.4 | 93.4 % (-0.3 dB) | 192 | 110.5 | 9.7 | 3965 | 5607 |
| 12 m | 24.94 | 3.08 | 10 | 1909.67 | 76.0 | 96.2 % (-0.2 dB) | 121 | 205.5 | 7.1 | 3420 | 4836 |
| 10 m | 28.5 | 3.08 | 7 | 3256.50 | 80.9 | 97.6 % (-0.1 dB) | 82 | 345.5 | 5.5 | 3014 | 4263 |

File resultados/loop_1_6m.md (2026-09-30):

# Loop magnético Ø 1.6 m – 22 mm – 100 W

Loop circular (u octogonal equivalente) de **1.6 m de diámetro** (perímetro 5.03 m) en tubo de cobre de **22 mm**. Capacidad parásita estimada 4.1 pF (ya restada). Resistencia extra de uniones/soldaduras 5 mΩ. Lazo de acoplo recomendado: Ø 32 cm.

⚠️ La tensión en el condensador es la de un loop perfectamente adaptado: con 100 W aparecen varios kV. No toques el loop transmitiendo.

| Banda | f (MHz) | L (µH) | C necesaria (pF) | R rad (mΩ) | R pérd (mΩ) | Eficiencia | Q cargado | Ancho banda (kHz) | I loop (A) | V cond @100 W (V rms) | V pico |
|---|---|---|---|---|---|---|---|---|---|---|---|
| 80 m | 3.65 | 4.39 | 429 | 2.77 | 41.2 | 6.3 % (-12.0 dB) | 1145 | 3.2 | 47.7 | 4800 | 6789 |
| 60 m | 5.36 | 4.39 | 197 | 12.88 | 48.9 | 20.9 % (-6.8 dB) | 1197 | 4.5 | 40.2 | 5949 | 8413 |
| 40 m | 7.1 | 4.39 | 110 | 39.64 | 55.5 | 41.7 % (-3.8 dB) | 1029 | 6.9 | 32.4 | 6348 | 8978 |
| 30 m | 10.12 | 4.39 | 52 | 163.62 | 65.3 | 71.5 % (-1.5 dB) | 610 | 16.6 | 20.9 | 5833 | 8250 |
| 20 m | 14.2 | 4.39 | 24 | 634.28 | 76.4 | 89.2 % (-0.5 dB) | 276 | 51.5 | 11.9 | 4645 | 6570 |
| 17 m | 18.12 | 4.39 | 13 | 1681.74 | 85.7 | 95.2 % (-0.2 dB) | 141 | 128.2 | 7.5 | 3759 | 5316 |
| 15 m | 21.2 | 4.39 | 9 | 3151.16 | 92.3 | 97.2 % (-0.1 dB) | 90 | 235.2 | 5.6 | 3246 | 4591 |
| 12 m | 24.94 | 4.39 | 5 | 6035.48 | 99.6 | 98.4 % (-0.1 dB) | 56 | 444.9 | 4.0 | 2777 | 3927 |
| 10 m | 28.5 | 4.39 | 3 | 10292.14 | 106.2 | 99.0 % (-0.0 dB) | 38 | 754.1 | 3.1 | 2437 | 3447 |

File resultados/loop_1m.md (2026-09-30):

# Loop magnético Ø 1.0 m – 22 mm – 100 W

Loop circular (u octogonal equivalente) de **1.0 m de diámetro** (perímetro 3.14 m) en tubo de cobre de **22 mm**. Capacidad parásita estimada 2.6 pF (ya restada). Resistencia extra de uniones/soldaduras 5 mΩ. Lazo de acoplo recomendado: Ø 20 cm.

⚠️ La tensión en el condensador es la de un loop perfectamente adaptado: con 100 W aparecen varios kV. No toques el loop transmitiendo.

| Banda | f (MHz) | L (µH) | C necesaria (pF) | R rad (mΩ) | R pérd (mΩ) | Eficiencia | Q cargado | Ancho banda (kHz) | I loop (A) | V cond @100 W (V rms) | V pico |
|---|---|---|---|---|---|---|---|---|---|---|---|
| 80 m | 3.65 | 2.45 | 774 | 0.42 | 27.6 | 1.5 % (-18.2 dB) | 1001 | 3.6 | 59.7 | 3352 | 4741 |
| 60 m | 5.36 | 2.45 | 358 | 1.96 | 32.4 | 5.7 % (-12.4 dB) | 1199 | 4.5 | 53.9 | 4446 | 6288 |
| 40 m | 7.1 | 2.45 | 203 | 6.05 | 36.6 | 14.2 % (-8.5 dB) | 1281 | 5.5 | 48.4 | 5291 | 7482 |
| 30 m | 10.12 | 2.45 | 98 | 24.97 | 42.7 | 36.9 % (-4.3 dB) | 1151 | 8.8 | 38.4 | 5985 | 8464 |
| 20 m | 14.2 | 2.45 | 49 | 96.78 | 49.6 | 66.1 % (-1.8 dB) | 746 | 19.0 | 26.1 | 5708 | 8072 |
| 17 m | 18.12 | 2.45 | 29 | 256.61 | 55.4 | 82.2 % (-0.8 dB) | 447 | 40.6 | 17.9 | 4989 | 7056 |
| 15 m | 21.2 | 2.45 | 20 | 480.83 | 59.5 | 89.0 % (-0.5 dB) | 302 | 70.3 | 13.6 | 4436 | 6273 |
| 12 m | 24.94 | 2.45 | 14 | 920.94 | 64.2 | 93.5 % (-0.3 dB) | 195 | 128.1 | 10.1 | 3865 | 5466 |
| 10 m | 28.5 | 2.45 | 10 | 1570.46 | 68.2 | 95.8 % (-0.2 dB) | 134 | 213.1 | 7.8 | 3424 | 4843 |

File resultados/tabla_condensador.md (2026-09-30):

# Capacidad máxima del condensador mariposa

Geometría: lóbulo 85°, R rotor 82.0 mm, R interior estátor 16.0 mm → área de solape por lóbulo = 4798 mm².

`calc` = capacidad ideal (placas paralelas, sin bordes), mismo criterio que la tabla de TA2WK. Con 3 mm el modelo coincide con TA2WK dentro de ±3 %. Para 4–6 mm TA2WK da valores algo menores (calculadora KI6GD con otra definición de hueco): usa el menor de los dos como valor seguro y **mide siempre con un medidor LCR** al terminar.

| Juegos | Placas rotor | Placas estátor | 3 mm: calc / TA2WK (pF) | 4 mm: calc / TA2WK (pF) | 5 mm: calc / TA2WK (pF) | 6 mm: calc / TA2WK (pF) |
|---|---|---|---|---|---|---|
| 5 | 4 | 10 | 57 / 58 | 42 / 39 | 34 / 29 | 28 / 23 |
| 10 | 9 | 20 | 127 / 131 | 96 / 87 | 76 / 66 | 64 / 53 |
| 15 | 14 | 30 | 198 / 204 | 149 / 136 | 119 / 102 | 99 / 79 |
| 16 | 15 | 32 | 212 | 159 | 127 | 106 |
| 20 | 19 | 40 | 269 / 277 | 202 / 185 | 161 / 139 | 135 / 110 |
| 22 | 21 | 44 | 297 | 223 | 178 | 149 |
| 25 | 24 | 50 | 340 | 255 | 204 | 170 |
| 27 | 26 | 54 | 368 | 276 | 221 | 184 |
| 30 | 29 | 60 | 411 / 423 | 308 / 282 | 246 / 212 | 205 / 163 |

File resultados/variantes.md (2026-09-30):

# Versiones propuestas del condensador (para loop Ø 1.0 m, tubo 22 mm)

## Versión A · QRP / portable

- Separación rotor-estátor: **3 mm** → separador entre placas de estátor **7 mm** (1 tuerca + 3 arandelas)
- Juegos: **16** → 32 placas de estátor (16 por lado) + 15 placas de rotor
- Cmax ≈ **212 pF** (ideal) / 231 pF con bordes · Cmin estimada ≈ **19 pF**
- Tensión práctica admisible ≈ **3000 V rms** (ruptura teórica aire seco ≈ 18 kV pico)
- Longitud del paquete de placas: **106 mm**

| Banda | C necesaria (pF) | ¿Sintoniza? | V a potencia nominal (V rms) | Potencia máx. segura (W) |
|---|---|---|---|---|
| 80 m | 774 | ❌ poca C | 1499 | — |
| 60 m | 358 | ❌ poca C | 1988 | — |
| 40 m | 203 | ✅ | 2366 | 32 |
| 30 m | 98 | ✅ | 2676 | 25 |
| 20 m | 49 | ✅ | 2553 | 28 |
| 17 m | 29 | ✅ | 2231 | 36 |
| 15 m | 20 | ✅ | 1984 | 46 |
| 12 m | 14 | ❌ Cmin alta | 1728 | — |
| 10 m | 10 | ❌ Cmin alta | 1531 | — |

## Versión B · 50 W

- Separación rotor-estátor: **4 mm** → separador entre placas de estátor **9 mm** (2 tuercas + 1 arandela)
- Juegos: **22** → 44 placas de estátor (22 por lado) + 21 placas de rotor
- Cmax ≈ **223 pF** (ideal) / 247 pF con bordes · Cmin estimada ≈ **20 pF**
- Tensión práctica admisible ≈ **4300 V rms** (ruptura teórica aire seco ≈ 24 kV pico)
- Longitud del paquete de placas: **190 mm**

| Banda | C necesaria (pF) | ¿Sintoniza? | V a potencia nominal (V rms) | Potencia máx. segura (W) |
|---|---|---|---|---|
| 80 m | 774 | ❌ poca C | 2370 | — |
| 60 m | 358 | ❌ poca C | 3144 | — |
| 40 m | 203 | ✅ | 3741 | 66 |
| 30 m | 98 | ✅ | 4232 | 52 |
| 20 m | 49 | ✅ | 4036 | 57 |
| 17 m | 29 | ✅ | 3528 | 74 |
| 15 m | 20 | ✅ | 3137 | 94 |
| 12 m | 14 | ❌ Cmin alta | 2733 | — |
| 10 m | 10 | ❌ Cmin alta | 2421 | — |

## Versión C · 100 W

- Separación rotor-estátor: **5 mm** → separador entre placas de estátor **11 mm** (2 tuercas + 3 arandelas)
- Juegos: **27** → 54 placas de estátor (27 por lado) + 26 placas de rotor
- Cmax ≈ **221 pF** (ideal) / 250 pF con bordes · Cmin estimada ≈ **20 pF**
- Tensión práctica admisible ≈ **5900 V rms** (ruptura teórica aire seco ≈ 30 kV pico)
- Longitud del paquete de placas: **287 mm**

| Banda | C necesaria (pF) | ¿Sintoniza? | V a potencia nominal (V rms) | Potencia máx. segura (W) |
|---|---|---|---|---|
| 80 m | 774 | ❌ poca C | 3352 | — |
| 60 m | 358 | ❌ poca C | 4446 | — |
| 40 m | 203 | ✅ | 5291 | 124 |
| 30 m | 98 | ✅ | 5985 | 97 |
| 20 m | 49 | ✅ | 5708 | 107 |
| 17 m | 29 | ✅ | 4989 | 140 |
| 15 m | 20 | ❌ Cmin alta | 4436 | — |
| 12 m | 14 | ❌ Cmin alta | 3865 | — |
| 10 m | 10 | ❌ Cmin alta | 3424 | — |

**Notas**

- *Potencia máx. segura* = potencia a la que la tensión del loop iguala la tensión práctica del condensador (criterio TA2WK ≈ 1–1,2 kV/mm). En SSB/CW puedes estirar algo; en FT8/RTTY (100 % ciclo) respeta el valor.
- Si Cmin impide llegar a 12/10 m, quita placas (el diseño es modular) o usa un loop más pequeño para esas bandas.

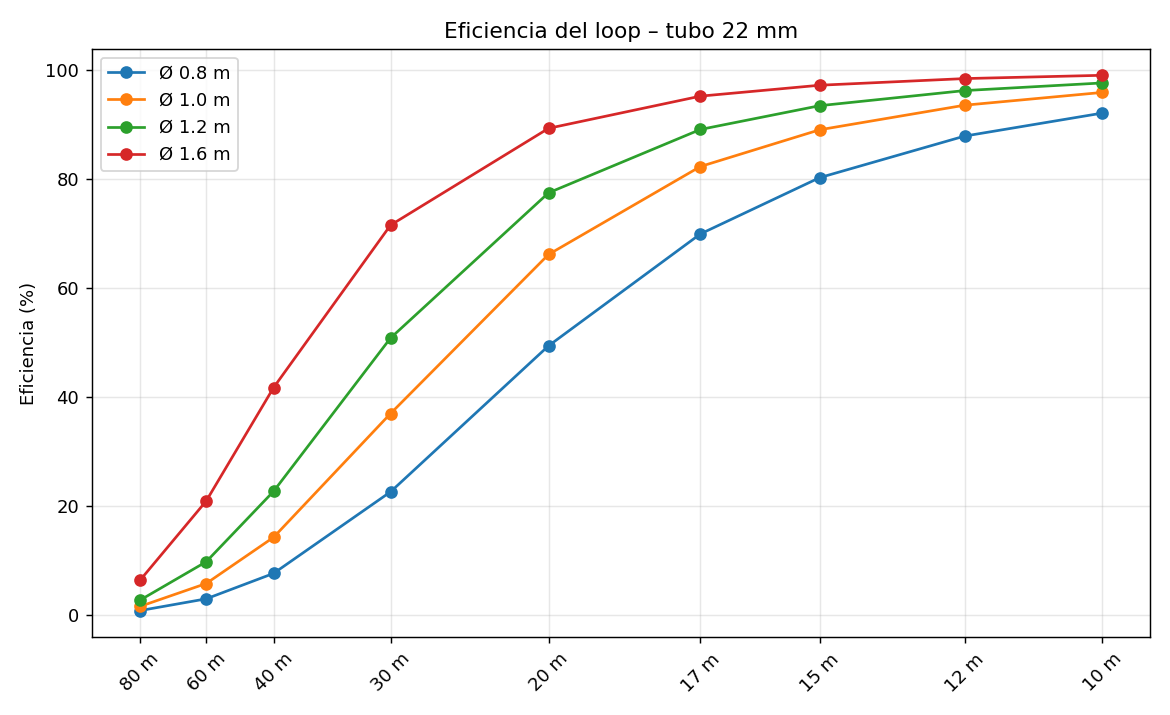
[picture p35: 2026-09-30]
resultados/eficiencia_loop.png

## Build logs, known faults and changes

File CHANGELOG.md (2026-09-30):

# Cambios

## v1.0.0 — 2026-09-30

- Cálculo del condensador mariposa (3 versiones) y de la loop magnética (0,8–1,6 m).
- Planos DXF/SVG de corte láser: rotor, estátor y tapa.
- Piezas imprimibles en 3D (OpenSCAD paramétrico + STL).
- Firmware ESP32 de autoajuste con simulación en PC.
- Guía paso a paso, montaje, fórmulas y dónde comprar en Murcia.

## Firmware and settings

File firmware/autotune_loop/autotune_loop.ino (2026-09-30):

/*
  AUTOAJUSTE PARA ANTENA LOOP MAGNÉTICA – condensador mariposa motorizado
  ESP32 + TMC2209 + NEMA17 con reductora 27:1 + sensor Hall A3144 + puente de ROE (tipo Bruene)

  Uso:
   - Selecciona banda (BANDA) -> el motor va a la posición aprendida (o al preset calculado).
   - Emite una PORTADORA de 5–10 W (modo AM/FM/CW o TUNE) y pulsa TUNE -> busca el mínimo de ROE.
   - ARRIBA/ABAJO: retoque fino manual (mantener pulsado = continuo).
   - TUNE mantenido 2 s -> busca home (Cmin).
   - Página web: conéctate a la WiFi "LoopTuner" y abre http://192.168.4.1
   - Puerto serie 115200: h (home) t (tune) u/d (paso) b<n> (banda) p<n> (posición) s (estado)

  Librerías (solo si USAR_OLED=1): Adafruit SSD1306 + Adafruit GFX.
  Placa: "ESP32 Dev Module" (paquete esp32 de Espressif para Arduino IDE).
*/
#include <Arduino.h>
#include <Preferences.h>
#include "config.h"
#include "bandas.h"
#if USAR_WIFI
#include <WiFi.h>
#include <WebServer.h>
WebServer web(80);
#endif
#if USAR_OLED
#include <Wire.h>
#include <Adafruit_GFX.h>
#include <Adafruit_SSD1306.h>
Adafruit_SSD1306 oled(128, 64, &Wire, -1);
bool oledOk = false;
#endif

Preferences prefs;
int32_t pos = 0;          // posición en micropasos (0 = home / Cmin)
bool homed = false;
int banda = 0;
float roe = 0;
String estado = "Inicio";

// ------------------------------------------------------------------ motor
bool driverOn = false;
void driver(bool on) {
  if (on == driverOn) return;
  digitalWrite(PIN_EN, on ? LOW : HIGH);
  driverOn = on;
  if (on) delay(5);
}

void moverRaw(int32_t destino, uint16_t us) {
  if (destino == pos) return;
  driver(true);
  int dir = destino > pos ? 1 : -1;
  digitalWrite(PIN_DIR, ((dir > 0) ^ INVERTIR_DIR) ? HIGH : LOW);
  delayMicroseconds(20);
  while (pos != destino) {
    digitalWrite(PIN_STEP, HIGH); delayMicroseconds(3);
    digitalWrite(PIN_STEP, LOW);  delayMicroseconds(us);
    pos += dir;
  }
}

// Movimiento con compensación de holgura: la aproximación final es SIEMPRE subiendo.
void moverA(int32_t destino, uint16_t us = US_RAPIDO) {
  destino = constrain(destino, 0, PASOS_MAX);
  if (destino < pos) moverRaw(destino - HOLGURA, us);
  moverRaw(destino, us);
}

bool hallActivo() { return digitalRead(PIN_HALL) == LOW; }

bool buscarHome() {
  estado = "Buscando home";
  driver(true);
  // si ya estamos sobre el imán, salir hacia arriba primero
  int32_t n = 0;
  pos = 0;
  while (hallActivo() && n++ < 4000) moverRaw(pos + 1, US_RAPIDO);
  // bajar hasta detectar el flanco (recorrido máx. = 1 vuelta de salida)
  int32_t limite = (int32_t)(370 * PASOS_GRADO);
  for (n = 0; n < limite && !hallActivo(); n++) moverRaw(pos - 1, n < limite - 2000 ? US_RAPIDO : US_LENTO);
  if (!hallActivo()) { estado = "ERROR: sin home"; driver(false); homed = false; return false; }
  pos = 0; homed = true;
  moverA(0);           // deja el rotor con la aproximación normalizada
  driver(false);
  estado = "Home OK";
  return true;
}

// ------------------------------------------------------------------ ROE
float mv(int pin) {
  uint32_t s = 0;
  for (int i = 0; i < MUESTRAS_ADC; i++) s += analogReadMilliVolts(pin);
  float v = (s / (float)MUESTRAS_ADC) * DIVISOR_ADC;
  return v > 20 ? v + CAIDA_DIODO_MV : 0;
}

// devuelve ROE, o -1 si no hay portadora
float medirRoe() {
  float f = mv(ADC_FWD), r = mv(ADC_REF);
  if (f < UMBRAL_FWD_MV) return -1;
  float g = constrain(r / f, 0.0f, 0.99f);
  return (1 + g) / (1 - g);
}

// ------------------------------------------------------------------ memoria
String clave(int b) { return String("b") + BANDAS[b].nombre; }
int32_t posBanda(int b) { return prefs.getInt(clave(b).c_str(), BANDAS[b].preset); }
void guardarBanda(int b, int32_t p) { prefs.putInt(clave(b).c_str(), p); }

// ------------------------------------------------------------------ barridos
// barrido ascendente [desde, hasta] con paso 'salto'; devuelve la mejor posición
bool barrer(int32_t desde, int32_t hasta, int32_t salto, uint16_t us, int32_t &mejorPos, float &mejorRoe) {
  desde = constrain(desde, 0, PASOS_MAX); hasta = constrain(hasta, 0, PASOS_MAX);
  moverA(desde, US_RAPIDO);
  mejorRoe = 99; mejorPos = desde;
  int subidas = 0;
  for (int32_t p = desde; p <= hasta; p += salto) {
    moverRaw(p, us);
    delay(3);
    float s = medirRoe();
    if (s < 0) { estado = "Sin portadora"; return false; }
    if (s < mejorRoe) { mejorRoe = s; mejorPos = p; subidas = 0; }
    else if (mejorRoe < ROE_OBJETIVO && ++subidas > 6) break;   // ya pasamos el mínimo
  }
  return true;
}

bool autoajuste() {
  if (!homed && !buscarHome()) return false;
  if (medirRoe() < 0) { estado = "Sin portadora"; return false; }
  estado = "Ajustando " + String(BANDAS[banda].nombre);
  int32_t fino = BANDAS[banda].paso_fino, grueso = fino * 4;
  int32_t centro = posBanda(banda), ventana = (int32_t)(VENTANA_GRADOS * PASOS_GRADO);
  int32_t p1; float s1;
  if (!barrer(centro - ventana, centro + ventana, grueso, US_RAPIDO, p1, s1)) { driver(false); return false; }
  if (s1 > ROE_NO_ENCONTRADA) {                       // no está cerca: barrido completo
    estado = "Barrido completo";
    if (!barrer(0, PASOS_MAX, grueso, US_RAPIDO, p1, s1)) { driver(false); return false; }
  }
  int32_t p2; float s2;
  if (!barrer(p1 - 3 * grueso, p1 + 3 * grueso, fino, US_LENTO, p2, s2)) { driver(false); return false; }
  int32_t p3; float s3;                                // pasada final paso a paso
  if (barrer(p2 - fino, p2 + fino, 1, US_LENTO, p3, s3) && s3 <= s2) p2 = p3;
  moverA(p2, US_LENTO);
  delay(20);
  roe = medirRoe();
  driver(false);                                        // sin corriente: menos ruido y calor
  if (roe > 0 && roe < ROE_NO_ENCONTRADA) { guardarBanda(banda, p2); estado = "OK ROE " + String(roe, 2); return true; }
  estado = "ROE alta: revisa acoplo";
  return false;
}

void irABanda(int b) {
  banda = (b + N_BANDAS) % N_BANDAS;
  prefs.putInt("banda", banda);
  if (!homed && !buscarHome()) return;
  estado = String("Banda ") + BANDAS[banda].nombre;
  moverA(posBanda(banda)); driver(false);
}

void retocar(int dir) {
  moverA(pos + dir * BANDAS[banda].paso_fino, US_LENTO);
  driver(false);
  float s = medirRoe(); if (s > 0) roe = s;
}

// ------------------------------------------------------------------ interfaz
void pantalla() {
#if USAR_OLED
  if (!oledOk) return;
  oled.clearDisplay(); oled.setTextColor(SSD1306_WHITE);
  oled.setTextSize(2); oled.setCursor(0, 0); oled.print(BANDAS[banda].nombre);
  oled.setTextSize(1); oled.setCursor(64, 0); oled.print(BANDAS[banda].khz); oled.print(" kHz");
  oled.setCursor(64, 9); oled.print(homed ? "home OK" : "sin home");
  oled.setCursor(0, 22); oled.print("Pos "); oled.print(pos); oled.print("  "); oled.print(pos / PASOS_GRADO, 1); oled.print((char)247);
  oled.setTextSize(2); oled.setCursor(0, 34); oled.print("ROE "); if (roe > 0) oled.print(roe, 2); else oled.print("--");
  oled.setTextSize(1); oled.setCursor(0, 56); oled.print(estado.substring(0, 21));
  oled.display();
#endif
}

String json() {
  return String("{\"banda\":\"") + BANDAS[banda].nombre + "\",\"khz\":" + BANDAS[banda].khz + ",\"pos\":" + pos +
         ",\"grados\":" + String(pos / PASOS_GRADO, 2) + ",\"roe\":" + String(roe, 2) + ",\"home\":" + (homed ? "true" : "false") +
         ",\"estado\":\"" + estado + "\"}";
}

void comando(const String &c, long n) {
  if (c == "h") buscarHome();
  else if (c == "t") autoajuste();
  else if (c == "u") retocar(+1);
  else if (c == "d") retocar(-1);
  else if (c == "U") { moverA(pos + 10 * BANDAS[banda].paso_fino); driver(false); }
  else if (c == "D") { moverA(pos - 10 * BANDAS[banda].paso_fino); driver(false); }
  else if (c == "b") irABanda(n);
  else if (c == "n") irABanda(banda + 1);
  else if (c == "p") { moverA(n); driver(false); }
  else if (c == "g") { guardarBanda(banda, pos); estado = "Guardado"; }
}

#if USAR_WIFI
const char PAGINA[] PROGMEM = R"HTML(<!doctype html><html lang=es><meta name=viewport content="width=device-width">
<title>Loop Tuner</title><style>body{font-family:sans-serif;max-width:420px;margin:auto;padding:12px;background:#111;color:#eee}
button{font-size:1.1em;margin:4px;padding:12px;min-width:88px;border-radius:8px;border:0;background:#e39a3b}
#r{font-size:2.4em}select{font-size:1.1em;padding:8px}</style>
<h2>Loop Tuner</h2><div id=r>ROE --</div><div id=i></div>
<p><select id=b onchange="c('b',this.value)"></select></p>
<p><button onclick="c('D')">&laquo;&laquo;</button><button onclick="c('d')">&laquo;</button><button onclick="c('u')">&raquo;</button><button onclick="c('U')">&raquo;&raquo;</button></p>
<p><button onclick="c('t')">AUTO TUNE</button><button onclick="c('g')">Guardar</button><button onclick="c('h')">Home</button></p>
<p style="color:#aaa">Para TUNE emite una portadora de 5–10 W.</p>
<script>const B=%BANDAS%;b.innerHTML=B.map((x,i)=>`<option value=${i}>${x}</option>`).join('');
function c(k,n=0){fetch(`/cmd?c=${k}&n=${n}`).then(e=>e.json()).then(v)}
function v(j){r.textContent='ROE '+(j.roe>0?j.roe.toFixed(2):'--');i.textContent=`${j.banda} · pos ${j.pos} (${j.grados}°) · ${j.estado}`;b.value=B.indexOf(j.banda)}
setInterval(()=>fetch('/estado').then(e=>e.json()).then(v),1500);</script></html>)HTML";
void iniciarWeb() {
  WiFi.softAP(WIFI_SSID, WIFI_PASS);
  web.on("/", [] {
    String s = FPSTR(PAGINA), l = "[";
    for (int i = 0; i < N_BANDAS; i++) l += String(i ? "," : "") + "\"" + BANDAS[i].nombre + "\"";
    s.replace("%BANDAS%", l + "]");
    web.send(200, "text/html", s);
  });
  web.on("/estado", [] { float s = medirRoe(); if (s > 0) roe = s; web.send(200, "application/json", json()); });
  web.on("/cmd", [] { comando(web.arg("c"), web.arg("n").toInt()); web.send(200, "application/json", json()); });
  web.begin();
}
#endif

struct Boton { uint8_t pin; bool antes; uint32_t t0; bool largo; };
Boton bt[4] = {{BTN_ARRIBA, 1, 0, 0}, {BTN_ABAJO, 1, 0, 0}, {BTN_TUNE, 1, 0, 0}, {BTN_BANDA, 1, 0, 0}};

void leerBotones() {
  for (int i = 0; i < 4; i++) {
    bool ahora = digitalRead(bt[i].pin);
    uint32_t t = millis();
    if (!ahora && bt[i].antes) { bt[i].t0 = t; bt[i].largo = false; }             // pulsado
    if (!ahora && !bt[i].largo && t - bt[i].t0 > 600) {                          // mantenido
      if (i == 0) retocar(+1);
      else if (i == 1) retocar(-1);
      else if (i == 2 && t - bt[i].t0 > 2000) { bt[i].largo = true; buscarHome(); }
      if (i < 2) { pantalla(); continue; }
    }
    if (ahora && !bt[i].antes && t - bt[i].t0 > 30 && t - bt[i].t0 < 600) {       // soltado (corta)
      if (i == 0) retocar(+1); else if (i == 1) retocar(-1);
      else if (i == 2) autoajuste(); else irABanda(banda + 1);
    }
    bt[i].antes = ahora;
  }
}

void setup() {
  Serial.begin(115200);
  pinMode(PIN_STEP, OUTPUT); pinMode(PIN_DIR, OUTPUT); pinMode(PIN_EN, OUTPUT);
  digitalWrite(PIN_EN, HIGH);
  pinMode(PIN_HALL, INPUT_PULLUP);
  for (auto &b : bt) pinMode(b.pin, INPUT_PULLUP);
  analogSetAttenuation(ADC_11db);
  prefs.begin("looptuner", false);
  banda = constrain(prefs.getInt("banda", 0), 0, N_BANDAS - 1);
#if USAR_OLED
  oledOk = oled.begin(SSD1306_SWITCHCAPVCC, 0x3C);
#endif
#if USAR_WIFI
  iniciarWeb();
#endif
  pantalla();
  if (HOMING_AL_ARRANCAR && buscarHome()) irABanda(banda);
  Serial.println(F("Loop Tuner listo. Comandos: h t u d U D b<n> n p<n> g s"));
}

void loop() {
  static uint32_t tp = 0;
  leerBotones();
#if USAR_WIFI
  web.handleClient();
#endif
  if (Serial.available()) {
    String l = Serial.readStringUntil('\n'); l.trim();
    if (l.length()) { if (l[0] != 's') comando(l.substring(0, 1), l.substring(1).toInt()); Serial.println(json()); }
  }
  if (millis() - tp > 500) { tp = millis(); float s = medirRoe(); if (s > 0) roe = s; pantalla(); }
}

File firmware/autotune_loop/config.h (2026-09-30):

// ===================== CONFIGURACIÓN DEL CONTROLADOR =====================
#pragma once

// --- Pines ESP32 DevKit v1 ---
#define PIN_STEP     25   // TMC2209 STEP
#define PIN_DIR      26   // TMC2209 DIR
#define PIN_EN       27   // TMC2209 EN (activo a nivel bajo)
#define PIN_HALL     23   // salida A3144 (colector abierto, pull-up 10k a 3,3 V en el controlador)
#define BTN_ARRIBA   32   // pulsadores a GND (pull-up interno)
#define BTN_ABAJO    33
#define BTN_TUNE     18   // pulsación corta = autoajuste · larga (2 s) = buscar home
#define BTN_BANDA    19
#define ADC_FWD      36   // VP: tensión directa del puente de ROE (tras divisor 1:2)
#define ADC_REF      39   // VN: tensión reflejada
// OLED SSD1306 0,96" I2C: SDA 21, SCL 22

#define USAR_OLED    1    // 0 si no montas pantalla
#define USAR_WIFI    1    // punto de acceso con página de control
#define WIFI_SSID    "LoopTuner"
#define WIFI_PASS    "73loop73"      // mínimo 8 caracteres

// --- Mecánica ---
#define INVERTIR_DIR     0      // pon 1 si "arriba" hace bajar la capacidad
#define HOLGURA          400    // pasos (>= holgura de la reductora, ~1,5°); aproximación final siempre subiendo
#define US_RAPIDO        150    // µs por micropaso en movimientos
#define US_LENTO         600    // µs por micropaso en el barrido fino
#define HOMING_AL_ARRANCAR 1

// --- Medida de ROE ---
#define DIVISOR_ADC      2.0f   // divisor 10k/10k en cada salida del puente (+ zener 3,3 V de protección)
#define CAIDA_DIODO_MV   200    // 1N5711 / BAT41 a baja corriente
#define UMBRAL_FWD_MV    300    // por debajo = no hay portadora
#define MUESTRAS_ADC     16
#define ROE_OBJETIVO     1.5f   // se da por buena
#define ROE_NO_ENCONTRADA 4.0f  // si el barrido local no baja de aquí, barrido completo
#define VENTANA_GRADOS   8.0f   // ± alrededor del preset/posición aprendida

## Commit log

2026-09-30 Condensador mariposa para loop magnética: cálculos, planos DXF, materiales en Murcia
    Claude-Session: https://claude.ai/code/session_01XDcqaZ4xraF21pRW9Ncuki
    [estator.dxf, lista_materiales.csv, loop_0_8m.csv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]
2026-09-30 Motorización con autoajuste: piezas 3D, firmware ESP32 y guía paso a paso
    - Piezas imprimibles (OpenSCAD paramétrico + STL): tapas, acoplamiento aislante,
    cuna del motor, soporte Hall, unión al mástil, cruceta, soportes del lazo, cajas
    - Firmware ESP32: home con Hall, barrido grueso/fino con compensación de holgura,
    memoria por banda, OLED, pulsadores y página web; simulación en PC
    - Posiciones del motor por banda y bandas.h generados desde el modelo
    - Esquemas de conjunto y cableado; guía completa de construcción
    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
    [acoplamiento_aislante.scad, acoplamiento_aislante.stl, caja_controlador.stl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]
2026-09-30 Preparar publicación: scripts, .gitattributes y CHANGELOG
    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
    [lista_materiales.csv, loop_0_8m.csv, loop_1_2m.csv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]
